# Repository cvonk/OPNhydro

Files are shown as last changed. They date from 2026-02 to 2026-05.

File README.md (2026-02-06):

# OPNhydro - ESP32-C6 Hydroponics Controller

A fully autonomous, data-rich hydroponics automation system with precision control, automatic top-off, and remote monitoring via Home Assistant.

## Features

- **Full Water Quality Monitoring**: pH, EC/TDS, dissolved oxygen, temperature
- **Environmental Monitoring**: Air temp/humidity, light intensity (lux/PPFD), VPD
- **Automatic Dosing**: pH up/down, two-part nutrients (A/B)
- **Automatic Top-Off (ATO)**: Ultrasonic level sensing with user-approved filling
- **Standalone Operation**: Local automation continues if Home Assistant is offline
- **Safety Features**: Float switch interlocks, dosing limits, timeout protection

## Project Structure

```
OPNhydroponics/
├── esphome/                    # ESPHome firmware configuration
│   ├── hydroponics-controller.yaml
│   ├── secrets.yaml.example
│   └── home-assistant-automations.yaml
├── hardware/
│   ├── ARCHITECTURE.md         # System design and pin assignments
│   ├── BOM.md                  # Bill of materials with pricing
│   ├── SCHEMATIC_DESIGN.md     # Circuit design guide
│   └── kicad/                  # KiCad PCB project
│       ├── hydroponics-controller.kicad_pro
│       └── README.md
├── docs/                       # Additional documentation
├── firmware/                   # Custom ESPHome components (if needed)
└── README.md
```

## Hardware Overview

| Category | Selection |
|---|---|
| System Type | NFT (Nutrient Film Technique), 20-80 plants |
| Controller | ESP32-C6-DevKitC-1-N8 (WiFi 6, Thread, USB-C) |
| Sensors | Atlas Scientific EZO (pH, EC, DO) + environmental |
| Actuators | 1× 12V main pump, 4× 12V dosing pumps, 1× 12V ATO valve |
| Integration | Home Assistant via ESPHome, standalone capable |

### Sensor Suite

| Sensor | Interface | Purpose |
|---|---|---|
| Atlas EZO-pH | I2C | Water pH monitoring |
| Atlas EZO-EC | I2C | Nutrient concentration (EC/TDS) |
| Atlas EZO-DO | I2C | Dissolved oxygen |
| DS18B20 | 1-Wire | Water temperature |
| HC-SR04 | GPIO | Water level (ultrasonic) |
| BME280 | I2C | Air temp, humidity, pressure |
| BH1750 | I2C | Light intensity (lux) |
| Float switches | GPIO | Safety level detection |

### Actuators

| Actuator | Voltage | Control |
|---|---|---|
| Main circulation pump | 12V DC | GPIO → MOSFET |
| pH Up dosing pump | 12V DC | GPIO → MOSFET |
| pH Down dosing pump | 12V DC | GPIO → MOSFET |
| Nutrient A dosing pump | 12V DC | GPIO → MOSFET |
| Nutrient B dosing pump | 12V DC | GPIO → MOSFET |
| ATO solenoid valve | 12V DC (NC) | GPIO → MOSFET |

## Quick Start

### 1. Hardware Setup

See [hardware/BOM.md](hardware/BOM.md) for the complete parts list.

**Minimum for testing:**
- ESP32-C6-DevKitC-1-N8 development board
- Atlas Scientific EZO-pH kit (or DFRobot for budget option)
- DS18B20 waterproof temperature probe
- Peristaltic dosing pump (12V)

### 2. ESPHome Configuration

1. Copy `esphome/secrets.yaml.example` to `esphome/secrets.yaml`
2. Fill in your WiFi credentials and generate API keys
3. Update DS18B20 address in the YAML (run I2C scan to find it)
4. Flash to ESP32-C6:

```bash
cd esphome
esphome run hydroponics-controller.yaml
```

### 3. Home Assistant Integration

1. The device will auto-discover in Home Assistant
2. Add the provided automations from `home-assistant-automations.yaml`
3. Create a dashboard with the exposed entities

## Local Automation

The controller runs standalone pH and EC control without Home Assistant:

**pH Control (every 5 minutes):**
- If pH < (target - tolerance): dose pH Up
- If pH > (target + tolerance): dose pH Down
- Respects lockout timer (default 5 min between doses)
- Respects daily limits (default 50 mL/day)

**EC Control (every 10 minutes):**
- If EC < (target - tolerance): dose Nutrient A, then B
- Only doses if pH is within range (5.5-6.5)
- Respects same lockout and daily limits

**ATO (Automatic Top-Off):**
- Monitors water level via ultrasonic sensor
- When level drops below threshold (default 70%), requests approval
- User approves via Home Assistant notification or dashboard
- Fills until target level (95%) or timeout

## Safety Features

1. **Float Switch Interlocks**: Main pump stops if low level detected
2. **ATO Overflow Protection**: High float switch stops fill immediately
3. **Dosing Lockout**: Minimum time between doses prevents overdosing
4. **Daily Limits**: Maximum mL per day for each chemical
5. **Timeout Protection**: ATO fill times out after configurable period
6. **Fail-Safe Valve**: NC (normally closed) solenoid prevents flooding on power loss

## PCB Design

The custom PCB is designed for JLCPCB fabrication:

- **Size**: 100mm × 80mm
- **Layers**: 2-layer
- **Features**: Reverse polarity protection, TVS diodes, proper isolation

See [hardware/kicad/README.md](hardware/kicad/README.md) for design files and manufacturing instructions.

## Configuration Reference

### Setpoints (adjustable via Home Assistant)

| Parameter | Default | Range | Description |
|---|---|---|---|
| pH Target | 6.0 | 5.0-7.5 | Target pH value |
| pH Tolerance | 0.3 | 0.1-1.0 | Deadband before dosing |
| EC Target | 1500 µS/cm | 500-3000 | Target conductivity |
| EC Tolerance | 200 µS/cm | 50-500 | Deadband before dosing |
| Dose Amount | 2.0 mL | 0.5-20 | Per-dose volume |
| Lockout Time | 5 min | 1-30 | Min time between doses |
| Daily pH Limit | 50 mL | 10-200 | Max pH adjustment per day |
| Daily Nutrient Limit | 100 mL | 10-500 | Max nutrients per day |
| ATO Low Threshold | 70% | 50-90 | Level to trigger ATO request |
| ATO High Target | 95% | 80-100 | Level to stop filling |
| ATO Max Fill Time | 180s | 30-600 | Timeout for safety |

### Pin Assignment

See [hardware/ARCHITECTURE.md](hardware/ARCHITECTURE.md) for complete GPIO mapping.

## Cost Estimate

| Category | Cost |
|---|---|
| Microcontroller | $8 |
| Power Management | $15 |
| Water Quality Sensors (Atlas) | $350 |
| Environmental Sensors | $20 |
| Actuators | $75 |
| PCB + Connectors | $40 |
| Enclosure | $25 |
| **Total** | **~$530** |

Budget option with DFRobot sensors: ~$280

## Contributing

This is an open project. Contributions welcome:

- Bug reports and feature requests via Issues
- PCB improvements and alternative designs
- ESPHome component enhancements
- Documentation improvements

## License

See [LICENSE](LICENSE) file.

## Acknowledgments

- [ESPHome](https://esphome.io/) for the excellent ESP32 framework
- [Atlas Scientific](https://atlas-scientific.com/) for quality sensor documentation
- [Home Assistant](https://www.home-assistant.io/) for the automation platform

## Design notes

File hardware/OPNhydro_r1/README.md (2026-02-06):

# KiCad Project - Hydroponics Controller

## Project Setup

### Required KiCad Version
- KiCad 8.0 or later

### Required Libraries

Install these libraries before opening the project:

1. **ESP32 Symbols & Footprints**
   - Source: https://github.com/espressif/kicad-libraries
   - Contains ESP32-C6-WROOM-1 module

2. **Connector Libraries** (included in KiCad)
   - Connector_BarrelJack
   - Connector_JST
   - Connector_USB

3. **Custom/Third-Party**
   - LCSC component library (optional, for JLCPCB assembly)

### Library Installation

```bash
# Clone Espressif KiCad libraries
git clone https://github.com/espressif/kicad-libraries.git

# Add to KiCad:
# Preferences -> Manage Symbol Libraries -> Add (espressif.kicad_sym)
# Preferences -> Manage Footprint Libraries -> Add (espressif.pretty)
```

## Design Specifications

### Board Parameters
- **Size**: 100mm × 80mm
- **Layers**: 2
- **Copper weight**: 2oz (70µm) outer layers
- **Min trace width**: 0.3mm (signal), 1.0mm (power), 2.0mm (high power)
- **Min clearance**: 0.2mm (signal), 0.3mm (power), 0.5mm (high voltage)
- **Via size**: 0.8mm pad / 0.4mm drill
- **Finish**: HASL (lead-free) or ENIG

### Layer Assignment
- **F.Cu (Top)**: Signal routing, component pads
- **B.Cu (Bottom)**: Ground plane, power distribution
- **F.Silkscreen**: Component designators, polarity marks
- **B.Silkscreen**: Board info, version

### Net Classes

| Class | Track Width | Clearance | Via Size | Usage |
|---|---|---|---|---|
| Default | 0.3mm | 0.2mm | 0.8/0.4mm | Signal traces |
| Power | 1.0mm | 0.3mm | 1.0/0.5mm | 3.3V, 5V rails |
| HighPower | 2.0mm | 0.5mm | 1.2/0.6mm | 12V, pump/valve outputs |

## Schematic Hierarchy

```
hydroponics-controller.kicad_sch (Root)
├── power-input.kicad_sch        # 12V input, protection, connectors
├── power-regulators.kicad_sch   # Buck converter (12V→5V), LDO (5V→3.3V)
├── devkit-headers.kicad_sch     # ESP32-C6-DevKitC-1 pin headers
├── sensors-i2c.kicad_sch        # I2C bus, EZO connectors, BME280, BH1750
├── sensors-other.kicad_sch      # 1-Wire, ultrasonic, float switches
├── pump-drivers.kicad_sch       # MOSFET drivers for 6 outputs
└── status-led.kicad_sch         # WS2812B, optional OLED
```

## Component Placement Guidelines

### Critical Placement
1. **DevKit headers**: Center of board, USB-C edge accessible
2. **Buck converters**: Near power input, with heatsinking area
3. **MOSFETs**: Grouped near screw terminals for pumps/valve
4. **BNC connectors**: Board edge for panel mounting
5. **Decoupling caps**: Near EZO circuit power pins

### DevKit Mounting
- ESP32-C6-DevKitC-1-N8 mounts via 2×20 female pin headers (2.54mm pitch)
- Header row spacing: 22.86mm (900 mils)
- No antenna keep-out needed - antenna is on DevKit PCB
- USB-C accessible at DevKit edge

### Thermal Considerations
- MOSFETs: Add thermal vias under source pad
- Buck converters: Large copper pour for heatsinking
- LDO: Thermal pad connected to ground plane

## Connector Pinouts

### J1 - 12V Power Input (3.5mm Pluggable Terminal)
| Pin | Signal |
|-----|---|
| 1 | +12V |
| 2 | GND |

### J2 - Main Pump (3.5mm Pluggable Terminal)
| Pin | Signal |
|-----|---|
| 1 | PUMP+ (12V switched) |
| 2 | PUMP- (GND) |

### J3-J6 - Dosing Pumps (3.5mm Pluggable Terminal each)
| Pin | Signal |
|-----|---|
| 1 | PUMP+ (12V switched) |
| 2 | PUMP- (GND) |

### J7 - ATO Solenoid Valve (3.5mm Pluggable Terminal)
| Pin | Signal |
|-----|---|
| 1 | VALVE+ (12V switched) |
| 2 | VALVE- (GND) |

### J8-J10 - BNC Probe Connectors
- Panel-mount BNC female for pH, EC, DO probes
- Atlas probes use male SMA with included SMA-to-BNC adapter
- Connect to respective EZO circuit PRB input

### J11-J14 - I2C Sensors (JST-PH 4-pin, Qwiic compatible)
| Pin | Signal | Color |
|-----|---|---|
| 1 | GND | Black |
| 2 | 3.3V | Red |
| 3 | SDA | Blue |
| 4 | SCL | Yellow |

### J15 - 1-Wire (JST-PH 3-pin)
| Pin | Signal |
|-----|---|
| 1 | GND |
| 2 | DATA |
| 3 | 3.3V |

### J16 - Ultrasonic Sensor (JST-XH 4-pin)
| Pin | Signal |
|-----|---|
| 1 | VCC (5V) |
| 2 | TRIG |
| 3 | ECHO |
| 4 | GND |

### J17-J18 - Float Switches (JST-XH 2-pin each)
| Pin | Signal |
|-----|---|
| 1 | SWITCH |
| 2 | GND |

## Manufacturing Files

### Gerber Export Settings (JLCPCB)
- Gerber X2 format
- Include: F.Cu, B.Cu, F.Paste, B.Paste, F.Silkscreen, B.Silkscreen, F.Mask, B.Mask, Edge.Cuts
- Drill files: Excellon format, PTH and NPTH combined

### BOM Export
- Export as CSV for JLCPCB assembly
- Include: Reference, Value, Footprint, LCSC Part Number

### Pick & Place
- Export component positions for SMT assembly
- Origin: Aux origin or board origin (check JLCPCB requirements)

## Version History

| Version | Date | Changes |
|---|---|---|
| 1.0 | TBD | Initial design |

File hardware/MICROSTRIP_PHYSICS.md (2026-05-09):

<center>

# Field Theory for PCB Design

**"Signal Integrity from First Principles"**</center>

<figure>
  <center>
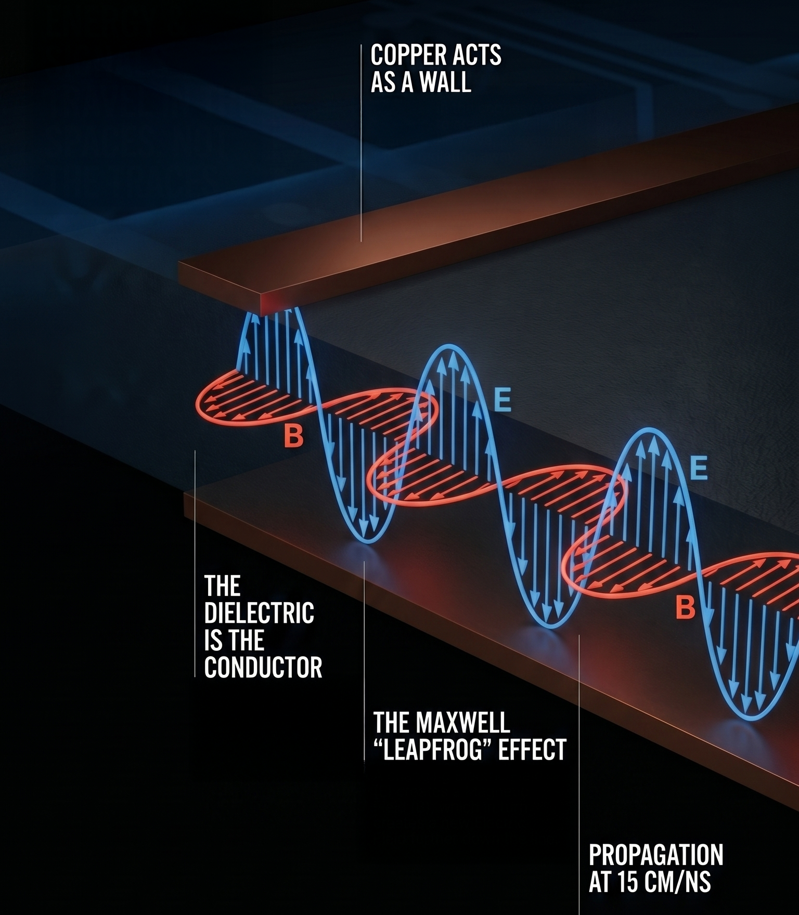
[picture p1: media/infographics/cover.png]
  
  </center>
</figure>
<style>
  .quote {
  position: relative;
  width: 95%;
  padding-left:4% !important;
  /*margin: 0 auto;*/
  /*line-height: 1.4;*/
  z-index: 600;
  overflow: visible;
  /*background-color: #f6f6f6;*/
}
.quote:before {
  position: absolute;
  top: -0.25em;
  left: 0;
  z-index: -300;
  font-family: Georgia, serif;
  content: "\201C";
  color: #999;
  opacity: 0.3;
  font-size: 2.3rem;
  font-weight: 600;
  text-shadow: none;
}
.quote cite {
  color: #bbb !important;
  display: block;
  font-style: normal;
  font-weight: 400;
  text-align: right;
  line-height: 1;
}
.quote.feynman:before {
  color: red;
}
.quote.feynman {
  /*color: cornflowerblue;*/
}
.important-note {
  position: relative;
  border-radius: 8px;
  overflow: hidden;
  padding: .8rem .2rem 0rem 5rem;
  margin: 0 0 1.2rem 0;
  background: #f1f3a2;
  background: -webkit-gradient(
    linear,
    0% 0%,
    0% 100%,
    from(rgba(247, 247, 210, 1)),
    to(rgba(240, 242, 155, 1))
  );
  background: -moz-linear-gradient(
    top,
    rgba(247, 247, 210, 1),
    rgba(240, 242, 155, 1)
  );
}
.important-note p {
  margin: 0;
  padding: 0;
}
.important-note .katex-display {
  margin: 4px;
}
.important-note .MathJax_Preview {
  display: none;
}
.important-note .icon {
  font-weight: 700;
  background: #ff7a18;
  background: -webkit-gradient(
    linear,
    0% 0%,
    0% 100%,
    from(#ffad71),
    to(#ff7a18)
  );
  background: -moz-linear-gradient(top, #ffad71, #ff7a18);
  color: #fff;
  padding: 0 0.3rem;
  font-size: 40px;
  margin-right: 0rem;
  position: absolute;
  left: 0;
  top: 0;
  height: 100%;
  width: unset;
  display: flex;
  align-items: center;
}
</style>

Modern high-speed electronic systems cannot be understood using lumped circuit models alone[^cantExplain]. As signal transition times decrease, the spatial extent of electromagnetic fields becomes comparable to the physical dimensions of PCB interconnects. Under these conditions, signal behavior is governed by the propagation of electromagnetic waves rather than by instantaneous circuit relationships.

Voltage and current remain useful quantities, but they are not fundamental. They arise from the underlying electric and magnetic fields, $\mathbf E$ and $\mathbf B$, which evolve in space and time according to Maxwell’s equations.
[^cantExplain]: Circuit theory cannot explain why a split in the ground plane causes a signal integrity problem, why energy travels in the dielectric rather than in the copper, or why crosstalk depends on field geometry rather than circuit topology.

A PCB trace together with its return path forms a transmission structure that guides electromagnetic energy. The conductors do not carry this energy in the conventional sense; instead, they establish boundary conditions that shape and confine the fields. The dominant portion of the signal energy resides in the dielectric region between conductors.

This field-based perspective provides a unified framework for understanding:
- signal propagation and transmission-line behavior
- crosstalk between adjacent traces
- power distribution network (PDN) transients
- electromagnetic interference (EMI) and radiation

Throughout this document, circuit models are used where appropriate, but always as approximations derived from the underlying field behavior.

Chapter 1 builds the field theory picture from first principles — starting with Maxwell's equations applied to a microstrip, and working through wave propagation, conductor response, rail collapse, crosstalk, and EMI. Chapter 2 translates that physics into concrete layout rules, stack-up choices and trace sizing.

<br />

---

<br />

## 1 Field Theory

> "Since the TTL days, there has been a four orders of magnitude change in the switching speed of transistors."  -- *Dan Beeker*

<br />

### 1.1 From Voltage Step to Electromagnetic Wave in the Dielectric

> "Energy and signals travel in the spaces not the traces"  -- *Ralph Morrison*

When a voltage step is applied to a PCB trace, it triggers the propagation of a coupled electromagnetic disturbance guided by the geometry of the conductors and the dielectric.

We examine how such a disturbance is created and how it propagates.
<br />

#### 1.1.1 Physical Setup

Consider a **microstrip** structure consisting of:
- a conducting trace,
- a return plane,
- a dielectric separating them.

<figure>
  <center>
  
  <figcaption><i>3D-view of the microstrip structure.</i></figcaption>
  </center>
</figure>

We define a right-handed coordinate system ($\hat x \times \hat y = \hat z$):
- **$\hat x$:** from the trace down to the return plane (normal to the conductors, through the dielectric)
- **$\hat y$:** transverse to the trace (in the plane of the board, perpendicular to the trace direction)
- **$\hat z$:** direction of propagation

A voltage step is applied at one end of the trace. The central question is: 

<div class="quote">

**What physical mechanism carries this signal forward?**
</div>
<br />

#### 1.1.2 Governing Equations

The fields are governed by two of [Maxwell's equations](https://coertvonk.com/physics/electromagnetism/magnetism/materials-and-maxwells-equations-30453):
$$  
  \begin{align}  
    \nabla \times \mathbf E &= -\frac{\partial \mathbf B}{\partial t}
    \tag{\text{Faraday}}
    \\
    \nabla \times \mathbf B &=
    \mu\,\mathbf J
    +\ 
    \mu\,\varepsilon\, \frac{\partial \mathbf E}{\partial t}
    \tag{\text{Ampère-Maxwell}} 
  \end{align}
$$ 

where:
- $\mathbf E$ is the electric field vector at each point in space
- $\mathbf B$ is the magnetic field vector at each point in space
- $\mathbf J$ is the conduction current density
- $\mu$ and $\varepsilon$ are constants for the material

In the dielectric region:
- no free charges: $\rho = 0$
- no conduction current: $\mathbf J = \mathbf 0$

<div class="important-note"><span class="icon">💡</span>

In the dielectric, the two equations reduce to:
$$
  \begin{align*}
    \nabla \times \mathbf{B} &= \color{red}\cancel{\color{black}\mu \, \mathbf{J}} \color{black} + \mu\,\varepsilon \frac{\partial \mathbf{E}}{\partial t}
    \tag{\text{source-free Ampère-Maxwell}} \\
    \nabla \times \mathbf{E} &= -\frac{\partial \mathbf{B}}{\partial t}
    \tag{\text{Faraday}}
  \end{align*}
$$
</div>

These relations show that **time-varying electric and magnetic fields generate each other**.
<br />

#### 1.1.3 Intuitive Picture

<div class="quote feynman">

  Now look — you've got a copper trace, and underneath it a big sheet of copper called the return plane. Between them, a thin slab of dielectric. That's it. That's the whole apparatus. And I want to tell you what happens when you flip a switch at one end and connect a battery.

  The instant you close the switch, there's a voltage between the trace and the plane. And whenever you have a voltage between two pieces of metal, there's an **electric field** between them. Bang — the field is just there, pointing from the trace down to the plane. Not in all of space, mind you — only right near the switch, because the rest of the trace hasn't heard the news yet.

  Now, here is where it gets interesting. The electric field went from zero to something. That's a change. And it turns out — and this is one of the most marvelous things in physics — that **a changing electric field makes a magnetic field**. Not "has a magnetic field associated with it." Makes one. Maxwell figured this out. The electric field changes in time, and a magnetic field curls up around it, right there in the dielectric.

  OK, so now we have a magnetic field. And it is also going from zero to something. It's changing in time too. And Faraday — long before Maxwell — figured out the other half of the story: **a changing magnetic field makes an electric field**. So the magnetic field we just made, by changing, makes another electric field — a little bit further along the trace than the one we started with.

  You see what's happening? The electric field made a magnetic field. The magnetic field made an electric field. The new electric field is further down the line. And now it is changing, so it makes another magnetic field, which makes another electric field, and off we go. The two fields are playing leapfrog[^LEAPFROG], and they're heading down the trace at an enormous speed.

  And how fast, exactly? In empty space these fields travel at the speed of light — that's what light *is*, by the way, the same kind of leapfrog. In the dielectric the fields go a little slower because the dielectric gets in their way. But still fast — about half the speed of light. Six inches in a nanosecond. *That's* how fast a signal really moves on your board.

  And that, really, is what every trace on every PCB is doing. It's not carrying electrons to some destination. It's guiding a little wave of energy. Isn't that something?
</div>

[^LEAPFROG]: In reality the two fields coexist at every point, but the "leapfrog" picture captures how each sustains the other.

<figure>
  <center>
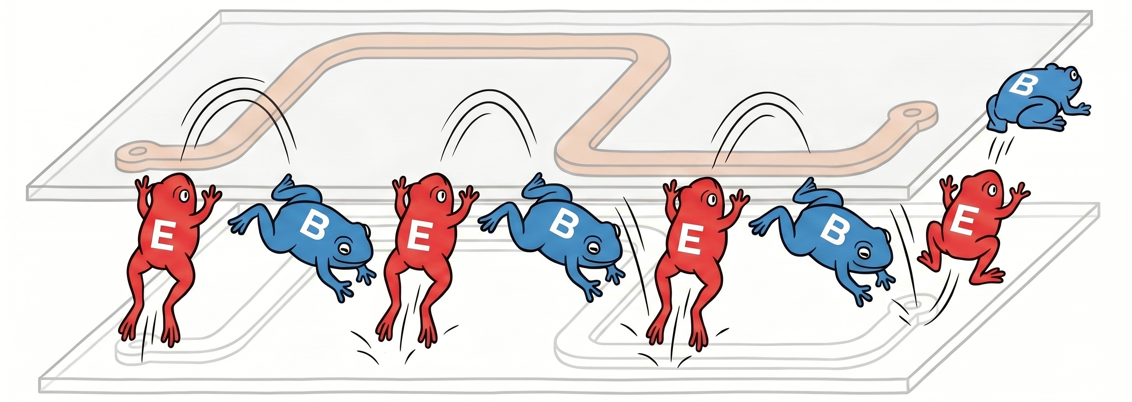
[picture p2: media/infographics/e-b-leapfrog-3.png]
  
  </center>
</figure>
<br />

#### 1.1.4 Wave Propagation Mechanism

<figure>
  <center>
  
  <figcaption><i>Side-view of the wavefront propagating along the trace, with <b>E</b> pointing from trace to return plane.</i></figcaption>
  </center>
</figure>

The intuition above pictures the wave as a sequence of E → B → E events. Maxwell's equations make this precise: a time variation at one point forces a spatial variation, and the wave's coherence comes from the two laws being applied everywhere simultaneously.

When a **voltage step** is applied to the trace:

1. An **electric field is established** ($\mathbf E$), between the trace and the return plane, near the source. Because it rises from zero, it is **time-varying**.
<br />

2. According to the Ampère–Maxwell law, an electric field in the $x$-direction that varies along the $z$-axis ($\tfrac{\partial E_x}{dt}\gt 0$) causes a **magnetic field** in the $y$-direction ($B_y$) that varies with $z$ — that means a little further along $z$, its value is rising from zero; it is **time-varying**. <details><summary>Expand if you ❤️ to see the derivation.</summary>
$$
  \begin{align*}
    \nabla \times \mathbf{B} &= \mu\,\varepsilon \frac{\partial \mathbf{E}}{\partial t}
    &({\text{Ampère-Maxwell}}) \\  
    \nabla\times\mathbf B &=
    \mu\varepsilon\frac{\partial E_x}{dt}\hat x, &(\mathbf{E}=E_x\,\hat x) \\
    \left(\frac{\partial B_z}{dy} - \frac{\partial B_y}{\partial z}\right)\cancel{\hat x} + \bcancel{\left(\ldots\right) \hat y} + \bcancel{\left(\ldots\right) \hat z} &=
    \mu\varepsilon\frac{\partial E_x}{dt} \cancel{\hat x}, &(\text{like terms}) \\
    -\frac{\partial B_y}{\partial z} &=
    \mu\varepsilon\frac{\partial E_x}{dt}, &(\frac{\partial B_z}{dy}=0)
  \end{align*}
$$
</details>
<br />

3. According to Faraday's law, an magnetic field in the $y$-direction that varies along the $z$-axis ($\tfrac{\partial B_y}{dt}\gt 0$) causes a **electric field** in the $x$-direction ($E_x$) that varies with $z$ — that means a little further along $z$, its value is rising from zero; it too is **time-varying**, and the disturbance has moved forward.[^leapfrogRigor]. <details><summary>Expand if you ❤️ to see the derivation.</summary>
$$
  \begin{align*}
    \nabla \times \mathbf{E} &= -\frac{\partial \mathbf{B}}{\partial t}
    &({\text{Faraday}}) \\  
    \nabla\times\mathbf E &=
    -\frac{\partial B_y}{dt}\hat y, &(\mathbf{B}=B_y\,\hat y) \\
    \bcancel{\left(\ldots\right)\hat x} + \left(\frac{\partial E_x}{\partial z} - \frac{\partial E_z}{\partial x}\right)\cancel{\hat y} +\bcancel{\left(\ldots\right)\hat z} &=
    -\frac{\partial B_y}{\partial t} \cancel{\hat y} & (\text{like terms}) \\
    \frac{\partial E_x}{\partial z} &=
    -\frac{\partial B_y}{dt}, &(\frac{\partial E_x}{dx}=0)
  \end{align*}
$$
</details>
<br />

Steps 2 and 3 continue throughout the structure. The result is not the transport of charge along the conductor, but the propagation of a **self-sustaining electromagnetic wave**.

Two conditions are essential:
- **Temporal variation:** the fields change in time at each point.
- **Spatial variation:** the fields differ from one location to another.

Together, they enforce propagation.

<div class="important-note"><span class="icon">💡</span>A voltage step on a trace and return plane launches an electromagnetic wave in the dielectric.
<br />
<br />
</div>

[^leapfrogRigor]: The "a little further down the line" framing in steps 2 and 3 is the leapfrog picture — useful for intuition, slightly loose as physics. The rigorous version: Maxwell-Ampère couples $\partial \mathbf E/\partial t$ here to $\partial \mathbf B/\partial z$ here, and the wavefront constraint $\partial/\partial t = -v\,\partial/\partial z$ converts the time variation into a spatial one. Appendix A.1 derives this coupling from Maxwell-Ampère; Appendix A.3 derives the wavefront constraint.

<br />

#### 1.1.5 Wave Equation and Velocity

The $\mathbf{E}$-field wave equation follows when you combine Faraday's law, the source-free Ampère–Maxwell law and Gauss's law.

<details>
  <summary>Expand if you ❤️ to see the derivation.</summary>

  Take the curl of Faraday's law
  $$
      \nabla \times (\nabla \times \mathbf E) = -\frac{\partial}{\partial t}(\nabla \times \mathbf B)
  $$

  Substitute the source-free Ampère–Maxwell into the right side
  $$
      \nabla \times (\nabla \times \mathbf E) = -\mu\,\varepsilon \frac{\partial^2 \mathbf E}{\partial t^2}
  $$

  Recall the vector identity
  $$
      \nabla \times (\nabla \times \mathbf E) = \nabla(\nabla \cdot \mathbf E) - \nabla^2\mathbf E
      \tag{\text{vector identity}}
  $$

  Expand the left side using this vector identity
  $$
      \nabla(\nabla \cdot \mathbf E) - \nabla^2\mathbf E = -\mu\,\varepsilon \frac{\partial^2 \mathbf E}{\partial t^2}
  $$

  Apply Gauss's law:
  $$
      \nabla \cdot \mathbf E = \frac{\rho}{\varepsilon}
      \tag{\text{Gauss}}
  $$

  In the source-free dielectric there are no charges ($\rho = 0$), so this becomes $\nabla \cdot \mathbf E = 0$. The first term vanishes, leaving:
  $$
      -\nabla^2 \mathbf E = -\mu\,\varepsilon\, \frac{\partial^2 \mathbf E}{\partial t^2}
  $$

  Or equivalently, the wave equation:
  $$
      \nabla^2 \mathbf E = \mu\,\varepsilon\, \frac{\partial^2 \mathbf E}{\partial t^2}
  $$
</details>
<br />

<div class="important-note"><span class="icon">💡</span>

Combining Faraday and Ampère-Maxwell yields the standard wave equation
$$
    \nabla^2 \mathbf E = \underbrace{\mu\,\varepsilon}_{1/v^2} \,\frac{\partial^2 \mathbf E}{\partial t^2}
$$
</div>

In this we recognize the generic wave equation for any quantity propagating at speed $v$:
<div class="quote">

$$
    \nabla^2 f = \frac{1}{v^2} \ \frac{\partial^2 f}{\partial t^2}
    \tag{\text{generic wave}}
$$
</div>

Comparing the two, term by term, gives the wave speed $v$:

<div class="important-note"><span class="icon">💡</span>

The propagation speed is only determined by material properties
$$
  v = \frac{1}{\sqrt{\mu \, \varepsilon}}
$$

where:
- $v$ is the wave speed
- $\mu$ is the permeability of the material
- $\varepsilon$ is the permittivity of the material 
</div>

<details>
  <summary>Expand to ❤️ how this gives the speed of light.</summary>

  In vacuum, the permeability constant $\mu = \mu_0$, and the permittivity constant $\varepsilon = \varepsilon_0$.
  $$
    \left\{
      \begin{align*}
        \mu_0 &= 4\pi \times 10^{-7} \text{ H/m} \\
        \varepsilon_0 &= 8.854 \times 10^{-12} \text{ F/m}
      \end{align*}
    \right.
  $$

  Substituting these constants:
  $$
      v = \frac{1}{\sqrt{4\pi \times 10^{-7} \times 8.854 \times 10^{-12}}} \approx 299.8 \times 10^6 \text{ m/s}
  $$

  That is the speed of light $c$ — derived entirely from electric and magnetic constants.
</details>
<br />

**In the dielectric** in a microstrip, the medium is not homogeneous (fields exist in both dielectric and air), and the mode is quasi-TEM rather than pure TEM. The propagation velocity (call it $v'$) is therefore determined by an **effective permittivity $\varepsilon_{\text{eff}}$**, so $\varepsilon = \varepsilon_{\text{eff}}\,\varepsilon_0$. The effective value is smaller than the bulk relative permittivity because part of the field is in air. For typical FR-4 microstrip ($\varepsilon_{\text{eff}} \approx 3.5$; bulk FR-4 has $\varepsilon_r \approx 4.3$):
$$
    v' = \frac{1}{\sqrt{4\pi \times 10^{-7} \times 3.5 \times 8.854 \times 10^{-12}}} \approx 16 \text{ cm/ns}
$$
<br />

#### 1.1.6 Interpretation

The signal does not propagate as a moving charge. The wave is the spatial pattern of $\mathbf E$ and $\mathbf B$ advancing through the dielectric, with the conductor surfaces forming the boundary that guides it. Energy resides in the dielectric volume, not in the copper.

For design, this reframes what a trace actually is. A trace is not a wire that carries current — it is one wall of a guiding structure whose other wall is the return plane. The integrity of the wave depends on what happens between those two walls. If the dielectric, the trace, and the return plane together form a clean boundary, the wave propagates undisturbed. If any one of them is compromised, the wave is disrupted, and the signal pays the price.

§1.2 examines what the conductors actually do to make this work: not transporting energy, but enforcing the boundary conditions that let the wave exist at all.
<br />

#### 1.1.7 Summary

A voltage step launches an electromagnetic wave that propagates in the dielectric, guided by the trace and its return plane. The propagation velocity is determined by material properties — about 16 cm/ns for FR-4 microstrip. The conductors do not carry the signal; they shape the boundary that lets the wave exist.
<br />

---

<br />

### 1.2 Conductor Response: Surface Charge and Current

Section 1.1 established that signal propagation occurs as an electromagnetic wave in the dielectric. The conductors do not transport the signal energy; instead, they respond to the incident fields and enforce the boundary conditions required for the wave to exist.

<div class="important-note"><span class="icon">💡</span>

**The wave is primary; the conductor response is a consequence.** The wave in the dielectric drives surface charge and surface current on the copper. Those surface quantities exist because Maxwell's equations require them at the boundary — not because they carry the signal.
</div>

The **free electrons** in the conductor respond in two forms:
- **surface charge**, associated with the electric field
- **surface current**, associated with the magnetic field

Both arise directly from Maxwell’s equations.
<br />

#### 1.2.1 Electric Field at the Conductor Boundary

In a microstrip, the electric field in the dielectric has two components:
- a dominant **normal** component $E_x$, perpendicular to the conductor surfaces (along the dielectric thickness)
- a smaller **longitudinal** component $E_z$, along the direction of propagation

<figure>
  <center>
  
  <figcaption><i>Side-view: E<sub>x</sub> (normal, dominant) and E<sub>z</sub> (longitudinal, small) components of the microstrip electric field.</i></figcaption>
  </center>
</figure>

These components produce distinct physical effects at the conductor surface.
<br />

#### 1.2.2 Intuitive Picture

<div class="quote feynman">

  So put it all together:
  - The wave is in the dielectric.
  - The *down-field* from the wave shoves electrons around on the copper surfaces. Those electrons build a wall that keeps the wave trapped in the dielectric.
  - The *along-field* from the wave pushes other electrons along the trace, giving you the little current you measure with your ammeter.

  And here's a small puzzle. Once the wavefront has passed your section, the wall of charge is built — fine, that's what walls do. But the *current* keeps flowing. Why? Because the wavefront is still out there ahead of you, still building walls farther down the line, and it needs charge to do it. The current through your already-charged section is feeding the section in front of you — like water in a pipe still flowing because somebody downstream is still drinking.

  The wave is the boss. The electrons are the help. And what the electrons do — the thing we call "current" — is not how the energy gets from here to there. The energy is out in the dielectric, in the fields. The current is just the electrons reacting to the field.

  You can also say this without ever mentioning an electron. The wave's $\mathbf E$ and $\mathbf B$ exist right up to the surface of the copper, but inside the copper they have to be zero — that's what good conductors do. So there's a jump at the surface, and nature does not allow that for free: wherever the perpendicular $\mathbf E$ has a jump, there must be **charge** to account for it; wherever the parallel $\mathbf B$ has a jump, there must be **current**. The metal has no choice.

  And that's really all there is to it. The hard part is believing it.
</div>

> Translating into formal terms: 
> - "down-field" → normal $E_x$ (perpendicular to the conductor surfaces);
> - "along-field" → longitudinal $E_z$ (along the direction of propagation).

<br />

#### 1.2.3 Surface Charge Formation (driven by $E_x$)

As the wavefront reaches a section of the conductor, the normal electric field $E_x$ rises from zero to a finite value.

This field exerts a force on the **free electrons**:
- *in the trace*, electrons move away from the dielectric-facing surface.
- *in the return plane*, electrons move toward the dielectric-facing surface.
<figure>
  <center>
  
  <figcaption><i>Side-view: Microstrip E<sub>x</sub> confinement.</i></figcaption>
  </center>
</figure>

This redistribution produces:
- **positive surface charge** on the underside of the trace
- **negative surface charge** on the top of the return plane

The system rapidly reaches a local equilibrium in which:
- The *net field inside the conductor is driven to zero*, because the surface charges generate their own electric field that opposes the external field.
- The *external field is confined to the dielectric*, since the electric field cannot extend into the conductor.
<br />

##### Boundary Condition

Following the more intuitive discussion above, here's the formal version.

<details>
  <summary>Expand if you ❤️ to see the derivation</summary>

  Imagine a conductor with a surface charge density $\sigma_s$ (charge per unit area) and normal vector $\hat n$ that points perpendicular to the conductor surface. To find the electric field just outside the surface, we place a very thin, small, cylindrical Gaussian "pillbox" so that it straddles the conductor surface.
  <figure>
    <center>
    
    <figcaption><i>Side-view close-up of pillbox straddling the trace/dielectric boundary.</i></figcaption>
    </center>
  </figure>

  Gauss's law in integral form states that the net electric flux through any closed surface ($S$) is directly proportional to the total electric charge ($Q_{enc}$) enclosed within that surface.

  <div class="quote">

  $$
      \oint_S \mathbf E \cdot d\mathbf a = \frac{Q_{enc}}{\varepsilon} \tag{\text{Gauss}}
  $$
  </div> 

  where $d \mathbf{a}$ is an infinitesimal vector element of the surface area, pointing outwards normal to the surface.

  A key property of a conductor in electrostatic equilibrium is that the electric field $\mathbf {E}$ inside the conducting material is zero, so the inside area doesn't contribute. With the height $h \to 0$, the side areas do not contribute either. This implies that the only flux passing through the pillbox comes from the bottom face.
  $$
    \begin{align*}
      \oint_{out} \mathbf E \cdot (A \hat n) &= \left( \mathbf{E} \cdot \hat n \right) A = \frac{Q_{enc}}{\varepsilon} \tag{$d\mathbf{a_{out}}=A\hat n$} \\
      \Rightarrow
      \varepsilon \left(\mathbf{E}\cdot\hat n \right)A &= Q_{enc} \tag{$Q_{enc} = \sigma_s A$}
    \end{align*}
  $$

  The enclosed charge is $Q_{enc} = \sigma_s A$
  $$
      \varepsilon \left(\mathbf{E}\cdot\hat n \right) \bcancel{A} = \sigma_s \bcancel{A}
  $$

  $\mathbf{E}\cdot\hat n$ is the component of the field normal to the surface ($E_x$):
  $$
      \varepsilon\, E_x = \sigma_s
  $$
</details>
<br />

<div class="important-note"><span class="icon">💡</span>

The relationship between surface charge density and the electric field follows from Gauss’s law:
$$
    \sigma_s = \varepsilon\, E_x
$$

where:
- $\sigma_s$ is the surface charge density (in C/m<sup>2</sup>).
- $E_x$ is the electric field just outside the conductor.
</div>

This surface charge distribution is not arbitrary. It is exactly the distribution required to:
- cancel the field inside the conductor
- confine the external field to the dielectric

Thus, **the conductor shapes the electric field** through the formation of surface charge.
<br />

#### 1.2.4 Surface Current (driven by $\mathbf B$ and $E_z$)

This section presents two views of the surface current — the same two arguments the intuition foreshadowed:
1. Given a magnetic field at the surface, what current must exist? ($\mathbf B \to \mathbf K$) — the formal "$\mathbf B$-jump → current" boundary argument.
2. How does current get established as the wave propagates? ($E_z \to \mathbf J$) — the dynamical "along-field pushes electrons" picture.
<br />

##### Magnetic Field $\mathbf B$ drives the need for a Surface Current

The magnetic field associated with the propagating wave is tangential to the conductor surface. Maxwell’s equations require that this field be supported by current at the boundary.

When the magnetic field from the trace tries to enter the return plane, it induces [eddy currents](https://coertvonk.com/physics/electromagnetism/magnetism/motional-emf-30242) that create their own opposite magnetic field. This prevents the magnetic field $\mathbf{B}$ from entering. The return plane is electrically large and a good conductor, so the field cannot escape underneath it either; it has no other choice but to **loop tightly around the trace** in the dielectric above.
<figure>
  <center>
  
  <figcaption><i>Cross-section of the microstrip. <b>B</b>-field curls around the trace.</i></figcaption>
  </center>
</figure>

<details>
  <summary>Expand if you ❤️ to see the derivation</summary>

  Zooming in on a small section of the trace/dielectric boundary, we see that the wave's $\mathbf B$ field is tangential to the trace surface. 
  <figure>
    <center>
    
    <figcaption><i>Cross-section close-up of Amperian loop straddling the trace/dielectric boundary.</i></figcaption>
    </center>
  </figure>

  Imagine a tiny rectangular "Amperian loop" straddling the bottom surface of the copper. Two sides — represented by the displacement vector $\mathbf L$ — run parallel to the surface (one inside the copper, one outside). Two sides of height $h$ run perpendicular to the surface.

  As we shrink the height $h \to 0$, the perpendicular sides contribute nothing. Inside the conductor, $\mathbf{B}_{in} = 0$. Therefore, the total path integral comes entirely from the outside leg:
  $$
    \oint \mathbf{B} \cdot d \mathbf{l} = \mathbf{B}_{out} \cdot \mathbf{L}
  $$

  The current passing through this loop is the surface current density $\mathbf K$ (amps per meter) crossing the loop, integrated along $\mathbf L$:
  $$
    I_{enc} = \mathbf K \cdot \mathbf L
  $$

  (Both $\mathbf B_{out}$ and $\mathbf K$ end up parallel to $\mathbf L$ along the outside leg, so each dot product reduces to a magnitude product $B_{out}\,L$ and $K\,L$.)

  Recall Ampère's law in integral form:
  <div class="quote">

  $$
    \oint \mathbf{B} \cdot d\mathbf{l} = \mu\, I_{enc}
  $$
  </div>

  Substitute $\oint \mathbf{B}\cdot d\mathbf{l}$ and $I_{enc}$ in Ampère's law:
  $$
    \begin{align*}
      \mathbf{B}_{out} \cdot \mathbf{L} &= \mu \left( \mathbf K \cdot \mathbf L \right) \\
      \Rightarrow\quad B_{out}\,\bcancel{L} &= \mu\, K\,\bcancel{L} \\
      \Rightarrow\quad \mathbf K &= \frac{1}{\mu}\,(\hat n \times \mathbf B_{\text{out}}) = \frac{1}{\mu}\, |\mathbf B_{\text{out}}|\, \hat z & \text{(right-hand rule)}
    \end{align*}
  $$ where $\hat n$ is the outward normal from the conductor. 
</details>
<br />

<div class="important-note"><span class="icon">💡</span>

Ampère's law forces a surface current [^sCurrent] in the propagation direction on the **trace**:
$$
    \mathbf K_{\text{trace}} = \frac{B_y}{\mu}\,\hat z
$$

The **return plane** carries an equal and opposite current (its outward normal is $-\hat x$, so the right-hand rule flips the sign):
$$
    \mathbf K_{\text{plane}} = -\frac{B_y}{\mu}\,\hat z
$$

where:
- $\mathbf{K}$ is the surface current in A/m
- $B_y$ is the transverse component of the magnetic field at the boundary

[^sCurrent]: $\mathbf K$ and $\sigma_s$ are **surface** densities — the boundary counterparts of the volume densities $\mathbf J$ (A/m², current per cross-sectional area) and $\rho$ (C/m³, charge per volume). In a *perfect conductor*, all the response squeezes into an infinitely thin layer at the surface, so the volume densities formally become delta-functions and the meaningful quantities are $\sigma_s$ (C/m²) and $\mathbf K$ (A/m).
</div>

This shows that:
- the **magnetic field determines the surface current**
- the current is not an independent driver, but a response to the field

In real conductors, this current is distributed over a thin layer of thickness equal to the **skin depth**, where the fields penetrate slightly into the material. The skin depth $\delta$ is approximately 2 μm in copper at 1 GHz (see Appendix A.4).

For a real conductor, the surface-current approximation $\mathbf K \approx \mathbf J \cdot \delta$ holds for as long as $\delta \ll d$, where $d$ is the thickness of the conductor.

<br />

##### Longitudinal Electric Field $E_z$ establishes the Surface Current

While the previous result expresses a boundary condition, the current must also be established dynamically as the wave propagates.

At the wavefront, the voltage varies rapidly with position, changing from full intensity behind the wave to zero ahead of it. This produces a longitudinal electric field ($E_z$):
$$
  E_z = - \frac{\partial V}{\partial z}
$$

<figure>
  <center>
  Current at the wavefront, driven by the longitudinal field E<sub>z</sub>.
  <figcaption><i>Side-view: Current at the wavefront, driven by E<sub>z</sub>.</i></figcaption>
  </center>
</figure>

This field drives electron drift along the conductor, giving rise to **conduction current**:
- *in the trace*, electrons drift opposite to the direction of propagation
- *in the return plane*, electrons drift in the direction of propagation

This is the dynamic mechanism by which the current required by the magnetic field boundary condition is created.
<br />

##### Charge–Current Coupling (Continuity)

As the wavefront advances:
- surface charge builds up on newly reached sections
- current flows to supply this charge

Surface charge and current are linked by the Continuity Equation, a fundamental law in physics that expresses the conservation of charge.
$$
  \nabla\cdot \mathbf J + \frac{\partial \rho}{\partial t} = 0
  \tag{Continuity}
$$

In surface form:
$$
  \nabla_s \cdot \mathbf K + \frac{\partial \sigma_s}{\partial t} = 0
$$

<details>
  <summary>Expand if you ❤️ to see the derivation</summary>

  The surface divergence operator $\nabla_s\cdot$ takes derivatives only in directions tangent to the surface — for our trace surface with normal $\hat x$, that's $\hat y$ and $\hat z$:
  $$
    \left(
    \frac{\partial K_y}{\partial y} + \frac{\partial K_z}{\partial z} \right)
    + \frac{\partial \sigma_s}{\partial t} = 0
  $$

  Surface current $\mathbf{K}$ only exists in the $z$-direction ($\mathbf{K} = K_z \hat z$), so we can rewrite this as:
  $$
    \bcancel{\frac{\partial K_y}{\partial y}}
    + \frac{\partial K_z}{\partial z}
    + \frac{\partial \sigma_s}{\partial t} = 0
  $$

  Recall the expression for the surface current $\mathbf K$ from the previous section:
  <div class="quote">

  $$
    \mathbf K = \frac{B_y}{\mu}\,\hat z
  $$
  </div>

  As we saw, $\mathbf{K}$ exists only in the $+z$-direction:
  $$
    K_z = \frac{B_y}{\mu}
  $$

  At the wavefront, $\sigma_s$ is ramping from zero to $\varepsilon E_x$ as the wave passes, so $\partial K_z/\partial z \neq 0$ — the current converges into the section to deposit the new charge.

  Because the wave moves at speed $v$, the field follows the form $E_x(z-vt)$. This **wavefront constraint** links a *change in time* to a *change in space*:
  $$
    \frac{\partial E_x}{\partial t} = -v\, \frac{\partial E_x}{\partial z}
  $$

  So $\partial/\partial t = -v\,\partial/\partial z$ for any field quantity. Apply that to surface charge conservation:
  $$
      \frac{\partial K_z}{\partial z} = v\,\frac{\partial \sigma_s}{\partial z}
  $$

  Integrate along $z$ on both sides. Both $K_z$ and $\sigma_s$ vanish ahead of the wavefront, so the integration constant is zero, leaving:
  $$
      K_z = v\,\sigma_s
  $$
  The surface current and surface charge are locked together by the wave speed.
</details>
<br />

<div class="important-note"><span class="icon">💡</span>

For a uniformly propagating wave, this leads to:
$$
  K_z = v\,\sigma_s
$$

where:
- $K_z$ is the longitudinal component of the surface current (along the propagation direction)
- $v$ is the propagation speed
- $\sigma_s$ is the surface charge density
</div>

This relation holds for a traveling wave and expresses that:
- surface charge and current move together
- both are part of the same propagating field structure
<br />

#### 1.2.5 Behavior Behind the Wavefront

Once the wavefront has passed:
- the normal field ($E_x$) becomes steady
- the longitudinal field ($E_z$) becomes small but nonzero (to sustain current against resistive losses in the conductor)

The surface charge at a given section is established once the wave has passed, but **current continues** through that section to supply the wavefront still advancing ahead.
<br />

#### 1.2.6 Interpretation

The conductor does not carry the signal in the conventional sense. Instead:
- **surface charge** enforces electric-field boundary conditions
- **surface current** sustains the magnetic field
- **electron motion is local**, responding to the passing wave

The signal itself remains a propagating electromagnetic field.

For design, this means surface charge and surface current are *consequences* of the wave, not independent variables. They cannot be controlled directly — they are whatever the wave demands at the boundary. Controlling them therefore reduces to controlling the wave's geometry: the trace shape, the dielectric thickness, the continuity of the return plane. Every layout decision that follows in chapter 2 is a way of shaping the wave so the conductor response stays clean and predictable. The next two sections build on this: §1.3 shows that the same wave that drives surface current also produces displacement current in the dielectric, closing the magnetic-field loop; §1.4 shows that growing or reshaping a current loop costs energy, and that this cost is what limits how fast a chip can switch.
<br />

#### 1.2.7 Summary

The response of a conductor to a propagating electromagnetic wave consists of:
- surface charge determined by the electric field
- surface current determined by the magnetic field

These quantities are fully constrained by Maxwell’s equations and are not independent drivers of signal propagation.
<br />

---

<br />

### 1.3 Sources of the Magnetic Field

Sections §1.1 and §1.2 established that signal propagation is an electromagnetic wave in the dielectric, and that the conductors respond through surface charge and current. We here examine a fundamental question:

> **What sustains the magnetic field as it spans both dielectric and conductor regions?**

<figure>
  <center>
  
  <figcaption><i>Cross-section of the microstrip. <b>B</b>-field curls around the trace.</i></figcaption>
  </center>
</figure>

<details>
  <summary>Expand if you ❤️ to see the simulated fields</summary>

  <figure>
    <center>
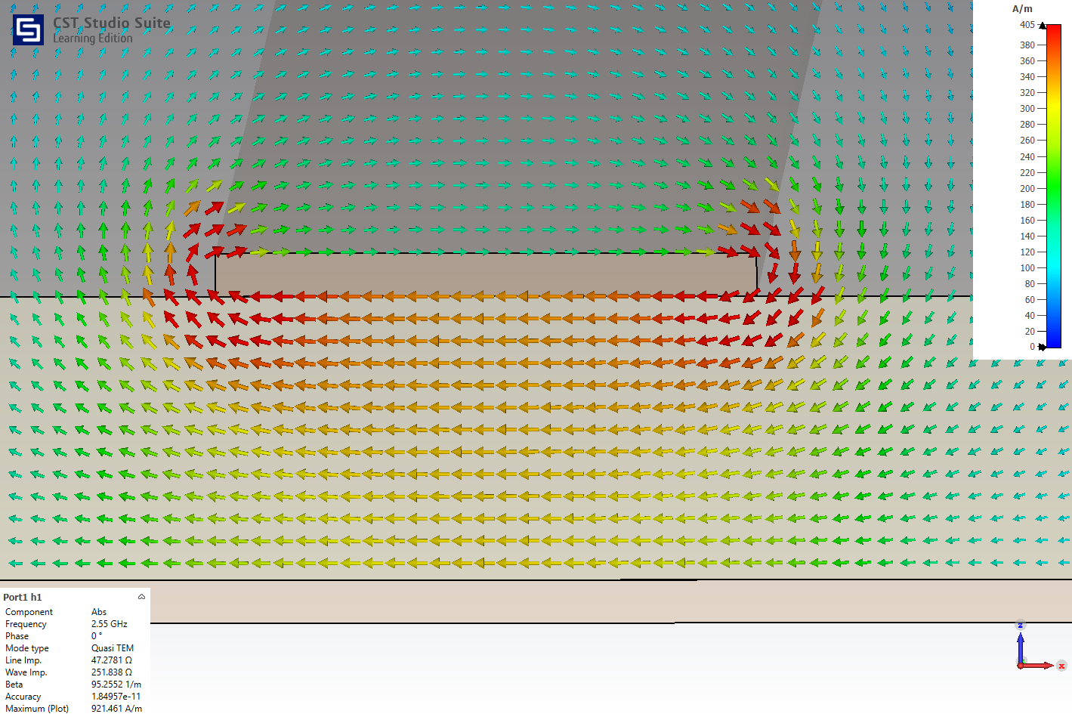
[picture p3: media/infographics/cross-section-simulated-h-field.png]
    
    <figcaption><i>Cross-section of the microstrip. CST simulation of <b>B</b>-field.</i></figcaption>
    </center>
  </figure>

  <figure>
    <center>
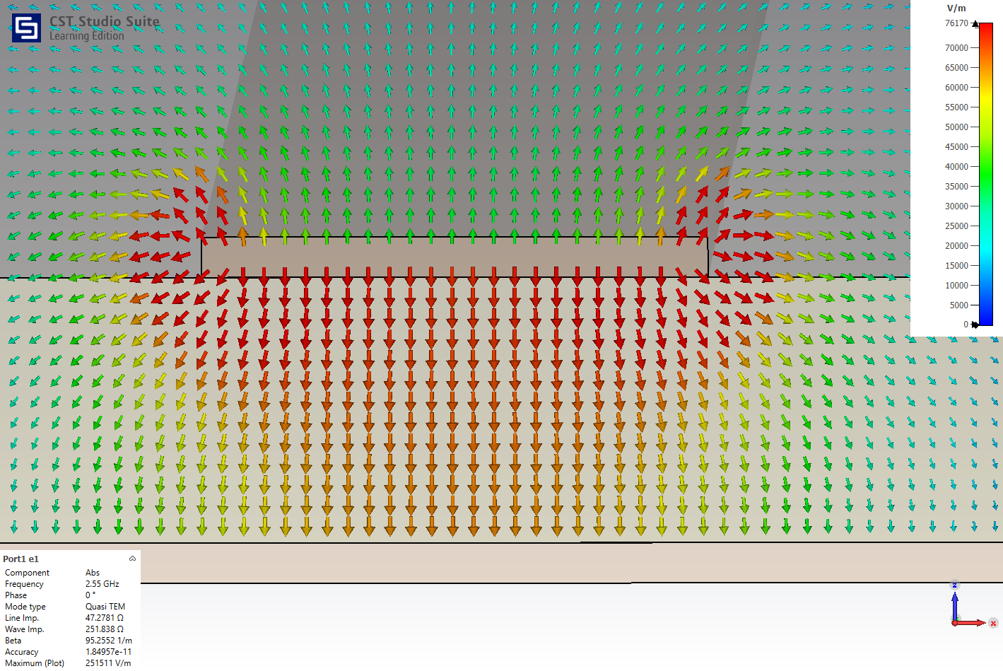
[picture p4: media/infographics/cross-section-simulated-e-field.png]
    
    <figcaption><i>Cross-section of the microstrip. CST simulation of <b>E</b>-field.</i></figcaption>
    </center>
  </figure>
</details>
<br />

#### 1.3.1 Intuitive Picture

<div class="quote feynman">
  You might think the magnetic field comes from the current in the copper — and that’s true, but only part of the story.

  Between the trace and the return plane, there’s no current flowing in the usual sense. But the electric field there is changing as the signal moves. And a changing electric field produces a magnetic field just as surely as a current does.

  So the magnetic field doesn’t start and stop at the copper. It wraps around the trace, passes through the dielectric, and closes on itself as a continuous structure.

  The current in the copper and the changing field in the dielectric are just two ways of sustaining the same magnetic field.

  If you tried to remove the displacement current term, the field would have nowhere to go — it would break at the boundary. Maxwell added that term so the field could remain whole.
</div>
<br />

#### 1.3.2 Sources of the Magnetic Field

The magnetic field is governed by the Ampère–Maxwell equation:
<div class="quote">

$$
    \nabla \times \mathbf B =
    \mu \, \mathbf J 
    \;+\;
    \mu\,\varepsilon\, \frac{\partial \mathbf E}{\partial t}
    \tag{Ampère–Maxwell}
$$
</div>

This identifies two sources:
- **conduction current $\mathbf J$**
- **displacement current $\varepsilon\frac{\partial\mathbf{E}}{\partial t}$**
<br />

#### 1.3.3 Region-Dependent Contributions

In different regions different terms dominate:

In the **conductor** (§1.2)[^k2j]:
- $\mathbf E \approx 0$ inside
- displacement current is negligible
- magnetic field is sustained by **conduction current $\mathbf J$**

In the **dielectric** (§1.1):
- $\mathbf J = 0$
- magnetic field is sustained by the **displacement current $\varepsilon\frac{\partial\mathbf{E}}{\partial t}$**

Inside a good conductor, both $\mathbf B$ and $\mathbf J$ decay together over the skin depth — most of the magnetic field of interest lives in the dielectric, with the surface current $\mathbf K$ matching the tangential $\mathbf B$ just outside (§1.2.4 boundary condition).

[^k2j]: The surface current $\mathbf K$ from §1.2 is just $\mathbf J$ integrated across the skin-depth layer where the current flows.
<br />

#### 1.3.4 Continuity Across the Interface

The governing equation is valid everywhere; only the dominant source term changes between regions.

The magnetic field forms a single continuous solution across the structure, even though:
- it is supported by conduction current in the conductor
- it is supported by displacement current in the dielectric

At the boundary, the tangential magnetic field is consistent with the required surface current. Without the displacement current term, $\nabla \times \mathbf B$ would have a jump at the dielectric boundary — Maxwell added that term precisely so the field could remain whole, as §1.3.1 put it.

**Closed current loop.** The continuity of the field is mirrored by a continuity of the *current* itself. Conduction current in the trace, displacement current in the dielectric, and conduction current in the return plane form one closed loop, required by the divergence-free constraint $\nabla \cdot \left(\mathbf J + \varepsilon\,\partial \mathbf E/\partial t \right) = 0$:

- forward in the trace (along $+\hat z$)
- across the dielectric in $+\hat x$ at the leading edge of a positive pulse (as $\mathbf E$ grows)
- back in the return plane (along $-\hat z$)
- across the dielectric in $-\hat x$ at the trailing edge (as $\mathbf E$ decays)

The trace and the return plane act like the plates of a propagating capacitor: conduction in the metal, displacement in the dielectric, conduction back. The two source terms are not parallel mechanisms — they are complementary segments of one continuous current loop.
<br />

#### 1.3.5 Interpretation

The magnetic field lives primarily in the dielectric, with a thin skin-depth penetration into the conductors — a single continuous field across the structure. Conduction current and displacement current are not separate phenomena; they are two contributions to the same electromagnetic field.

**Reconciling §1.2 and §1.3** 

§1.2 said "$\mathbf B$ determines $\mathbf K$"; §1.3 says "$\mathbf J$ sustains $\mathbf B$." These are not in conflict, and together they are the formal resolution of §1.3.1's "only part of the story." Maxwell-Ampère, $\nabla \times \mathbf B = \mu \mathbf J + \mu\varepsilon\,\partial \mathbf E/\partial t$, is an *identity* relating $\mathbf B$, $\mathbf J$, and $\partial \mathbf E/\partial t$ at every instant — none of the three is "the cause" of the others. The causal story is the one from §1.2: the wave in the dielectric is primary, and it drives the surface currents. Once those currents exist, Maxwell-Ampère bookkeeping requires them (together with the displacement current) to source the same continuous $\mathbf B$ field that drove them in the first place.

For design, the closed-loop view is the one that matters. The loop's geometry sets its inductance — that's what §1.4 turns into a design lever (rail collapse, decoupling, stack-up). Break the conduction return (a slot in the plane, a missing return via) or break the displacement-current path (an abrupt change in dielectric) and the loop opens up — the fields stop cancelling at a distance, and the failure modes of §1.5 (crosstalk) and §1.6 (EMI) follow directly.
<br />

#### 1.3.6 Summary

The magnetic field around a PCB trace is sustained by conduction current in the conductors and displacement current in the dielectric — together forming a single closed loop. Both terms are required by Maxwell's equations; neither alone is sufficient.
<br />

---

<br />

### 1.4 Power Distribution Network and Rail Collapse

The power distribution network (PDN) supplies the electromagnetic energy that active devices need to support changing current and voltage.

> **The central question: when a chip switches, where does the energy come from, and why isn't it always there in time?**
<br />

#### 1.4.1 Intuitive Picture

<div class="quote feynman">
  You ask the circuit for current right now.

  But current isn’t just charge moving — it’s a magnetic field wrapped around a path. And that field has to grow if the current grows. The bigger the path, the more field there is to grow — geometry matters.

  Growing a magnetic field takes energy, and it takes time. The supply can’t instantly reshape the field everywhere in the power network — the news has to travel from the chip to the supply and back, at the speed of light in the dielectric. Fast, but for sub-nanosecond logic, still not fast enough.

  So what happens? The device pulls what it can locally, and the voltage dips. That’s rail collapse.

  The decoupling capacitor is sitting right there with energy already stored in its electric field. It doesn’t need to wait. It hands over the charge immediately while the rest of the system catches up.

  The whole event is a negotiation between electric and magnetic fields trying to reconfigure themselves fast enough to meet the demand.
</div>
<br />

#### 1.4.2 Voltage Drop and Inductance

When a device switches, it requires a rapid increase in current. This corresponds to an increase in the magnetic field surrounding the current loop, with energy
$$
  W_L = \tfrac{1}{2} \, L \, I^2
$$
where $L$ is the inductance of the loop. Increasing current requires increasing this stored magnetic energy, and that energy has to be delivered through the PDN. The cost is a voltage drop:
<div class="quote">

$$
  \Delta V = L \, \frac{dI}{dt}
$$
</div>

If the voltage drop is large enough — what designers call **rail collapse** — the chip misinterprets logic levels or produces timing errors.
<br />

#### 1.4.3 Field Interpretation

The circuit relation $\Delta V = L\,dI/dt$ is the macroscopic shadow of a field-level event. The chip's switching current flows in a loop — out the supply pin, through the bond wires, package leads, PCB power and ground planes, and back. That loop has a magnetic field threaded through it, with energy density $\tfrac{1}{2}\mathbf B^2/\mu$ stored throughout the volume the field occupies — primarily inside the loop.

When the chip demands more current, the $\mathbf B$ field everywhere in that loop must grow. Two field-level constraints make this hard:

- **Energy delivery is wave-rate-limited.** The energy has to travel from the supply to the chip, and the supply only "knows" about the demand once it reaches it. Both legs are bounded by the speed of light in the dielectric ($\approx 16$ cm/ns in FR-4) — a 5 cm path adds $\approx 310$ ps each way, comparable to the rise time of fast logic.
- **A growing $\mathbf B$ field induces an opposing $\mathbf E$ field** (Faraday). This back-EMF appears as a voltage drop across the loop's inductance and subtracts from the rail at the chip pin.

The decoupling capacitor sidesteps both. Its electric field already stores energy locally — $W_C = \tfrac{1}{2}\,C\,V^2$, in the dielectric between its plates, millimeters from the load. The cap doesn't need to grow a $\mathbf B$ field across a long loop; it just releases stored $\mathbf E$-field energy through a much shorter path. The smaller the loop from cap to load, the smaller its inductance, and the less back-EMF the demand produces.

This swap — the cap's $\mathbf E$-field reservoir feeding the growing $\mathbf B$-field around the demand loop — is the "negotiation between electric and magnetic fields" the §1.4.1 intuition named. Every time the chip switches, an $\mathbf E$-field somewhere has to give up energy so a $\mathbf B$-field somewhere can grow.

Rail collapse is therefore the price the chip pays for these two constraints. The design levers that fight back are **minimize loop inductance** and **shorten the distance to local energy reservoirs**.
<br />

#### 1.4.4 Example

A typical microcontroller might switch 100 mA in 1 ns. A 5 mm trace between a poorly placed decoupling capacitor and the chip presents about $L = 5\,\text{nH}$ of parasitic inductance:
$$
  \Delta V = 5\,\text{nH} \cdot \frac{100\,\text{mA}}{1\,\text{ns}} = 500\,\text{mV}.
$$

A 500 mV dip on a 3.3 V rail is enough to upset logic levels on most chips. The lever is brutally simple: shorten the path.
<br />

#### 1.4.5 Summary

Rail collapse is the gap between how fast a chip's current loop demands $\mathbf B$-field energy and how fast the supply can deliver it. The two design levers — both turned into concrete rules in §2.1 — are minimizing loop inductance (tight power/return coupling, short via paths, continuous return planes) and placing local $\mathbf E$-field reservoirs (decoupling capacitors) close enough to the load that the speed-of-light round-trip stays under the chip's rise time.
<br />

---

<br />

### 1.5 Crosstalk

Crosstalk is interaction between electromagnetic fields associated with different conductors.

> **The central question: how does a signal on one trace end up on a neighboring trace that no wire connects it to?**
<br />

#### 1.5.1 Intuitive Picture

<div class="quote feynman">

Look. Two traces on a board, side by side. One of them is doing something — call it the *aggressor*, that's the standard name. The other is just sitting there, minding its own business. Call it the *victim*. Because in a moment, that's what it is.

Here's the trouble. When you draw the aggressor on your schematic, you picture its field as a neat little package tucked between the trace and the return plane underneath. But fields don't care about your schematic. Maxwell tells them where to go, and Maxwell says fields *spread*. Most of the energy stays where you want it, sure — but some of the electric field bulges sideways into the dielectric, and some of the magnetic loops swing out wider than the trace itself. The fields are leaky. They don't have to be. They just are.

And the victim is sitting right there in the leak. It didn't ask to be. The field doesn't ask permission.

When the aggressor's *voltage* swings, the electric field changes everywhere — including over the victim. And what does a changing electric field do to a piece of metal? It pushes charge around. So charge moves on the victim. That's **capacitive coupling**. The two traces, whether you wanted it or not, *are* a capacitor.

When the aggressor's *current* swings, the magnetic field changes everywhere — including through the little loop the victim makes with its own return path. And what does a changing magnetic field do to a loop? It drives a current around it, in the direction that *opposes the change* — Lenz's law, nature being stubborn about being pushed around. That's **inductive coupling**. The two trace-loops, whether you wanted it or not, *are* a transformer.

So far, both effects just add up. But here's the puzzle: they don't add up the same way at both ends of the victim.

The capacitive current splits and travels *both* ways down the victim. The inductive current, because of Lenz, flows only *one* way — backward, toward the aggressor's source.

So at the near end (the end nearest the source), both effects push the same way and they *reinforce*. **Near-end crosstalk** — substantial. At the far end, they push opposite ways and they *fight*. **Far-end crosstalk** — on a uniform line, almost cancels. Same physics. Opposite sign. Depends on which end you put your probe.

And once you see it, crosstalk stops looking like two circuits sneaking signals at each other. It's *one* electromagnetic field sloshing around between the aggressor and its return — and a second piece of copper that, through no fault of its own, found itself sitting where the field happens to be. Move the copper. Or confine the field. The fields never cared about your circuits to begin with.
</div>
<br />

#### 1.5.2 Geometry and Field Overlap

Consider two parallel microstrip traces above a common return plane:
- the **aggressor** trace carries a time-varying signal
- the **victim** trace is initially quiet

As a voltage step propagates along the aggressor, it generates:
- an electric field $\mathbf E$ between trace and return plane
- a magnetic field $\mathbf B$ looping around the trace

These fields are not perfectly confined to the region directly beneath the aggressor. A portion extends laterally into the surrounding dielectric. If the victim trace lies within this region, it is exposed to both fields. Each produces a different coupling mechanism — and both are direct consequences of Maxwell's equations.

<figure>
  <center>
  
  <figcaption><i>Cross-section: Capacitive coupling (<b>E</b> field fringing between traces) and inductive coupling (<b>B</b> field threading the victim loop).</i></figcaption>
  </center>
</figure>
<br />

#### 1.5.3 Capacitive Coupling (electric field)

The electric field terminates partly on the neighboring conductor, creating **mutual capacitance**.

<details>
  <summary>Expand if you ❤️ to see the derivation.</summary>

  Imagine two parallel traces on a PCB:
  - Trace 1 (Aggressor): has a time-varying voltage $V(t)$
  - Trace 2 (Victim): is affected by the electric field of Trace 1
  - $C_m$ (Mutual Capacitance): the capacitance between Trace 1 and Trace 2

By definition, the charge $Q$ induced on the victim trace due to the potential on the aggressor trace is proportional to the mutual capacitance: 
<div class="quote">

  $$
    Q = C_{m}\cdot V_{1}
  $$
</div>

From the Continuity Equation ($\nabla \cdot \mathbf{J} + \frac{\partial \rho}{\partial t} = 0$), we know that a change in charge over time results in a flow of current. Taking the time derivative of the charge equation:
$$
  \frac{dQ}{dt} = \frac{d}{dt}(C_m V_1)
$$

The current $I$ is defined as the rate of flow of charge ($I = dQ/dt$). Since $C_m$ is set by the trace geometry (constant), it pulls out of the derivative, leaving:
$$
  I_C = C_m \, \frac{dV}{dt}
$$
The capacitive coupling current on the victim is proportional to $dV/dt$ on the aggressor.
</details>

<div class="important-note"><span class="icon">💡</span>

A time-varying voltage on the aggressor produces a time-varying electric field. This induces surface charge on the victim trace, resulting in current:
$$
    I_C = C_m \ \frac{dV}{dt}
$$ where:
- $I_C$ is the current in the victim trace
- $C_m$ is the mutual capacitance
- $V$ is the voltage on the aggressor
</div>

Characteristics:
- proportional to the voltage transition rate $dV/dt$
- depends on the strength and spatial extent of the electric field
- increases with closer spacing, longer parallel runs and weaker field confinement
<br />

#### 1.5.4 Inductive Coupling (magnetic field)

The changing current in the aggressor generates a changing magnetic field. Part of this field links the loop formed by the victim trace.

<details>
  <summary>Expand if you ❤️ to see the derivation.</summary>

  By Faraday’s law, the changing magnetic flux induces an electric field:
  $$
      \nabla \times \mathbf{E} = -\frac{\partial \mathbf{B}}{\partial t} 
      \tag{\text{Faraday}}
  $$

  Integrate Faraday's law over the open surface $S$ of the victim loop:
  $$
    \iint_S (\nabla \times \mathbf{E}) \cdot d\mathbf{a} = -\iint_S \frac{\partial \mathbf{B}}{\partial t} \cdot d\mathbf{a}
  $$

  Using Stoke's Theorem, we convert the surface integral of the curl of $\mathbf E$ into a line integral of $\mathbf E$ around the closed boundary loop $C$.
  $$
    \oint_C \mathbf{E} \cdot d\mathbf{l} 
    = - \frac{d}{dt} \iint_S \mathbf{B} \cdot d\mathbf{a}
  $$

  The term on the left, $\oint_C \mathbf{E} \cdot d\mathbf{l}$, is the definition of electromotive force or **induced voltage** $V_{ind}$.

  The surface integral on the right is the definition of magnetic flux ($\Phi_m$) passing through the loop:
  <div class="quote">

  $$
    \Phi_m = \iint_S \mathbf{B} \cdot d\mathbf{a}
  $$
  </div>

  This simplifies the relationship to:
  $$
    V_L = - \frac{d\Phi_m}{dt}
  $$

  The magnetic flux ($\Phi_m$) threading through the victim loop is physically created by the current $I$ in the aggressor loop. Because the relationship is linear for most materials, we define **Mutual Inductance ($L_m$)** as the ratio of flux to current.
  $$
    \Phi_m \triangleq L_m I
  $$ where $L_m$ "hides" the geometry (distance, height and length) into a single constant.

  Finally, we substitute the definition of flux back into the Faraday result
  $$
    \begin{align*}
    V_L &= - \frac{d(L_m I )}{dt} \\
    &= - L_m\,\frac{d I}{dt}
    \end{align*}
  $$
</details>
<br />

<div class="important-note"><span class="icon">💡</span>

The changing magnetic flux creates an induced field that opposes the change that created it. The induced voltage:  
$$
  V_L = - L_m\frac{dI}{dt}
$$ where:
- $V_L$ is the induced voltage on the victim trace
- $L_m$ is the mutual inductance between the two trace-return-plane loops
- $I$ is the current in the aggressor trace
</div>

 It depends on how much of the aggressor's $\mathbf B$ field threads through the victim's loop — set by the physical distance between traces, the height above the return plane, and the length of the parallel run.

Characteristics:
- proportional to the rate of change of the aggressor's current $dI/dt$
- depends on loop geometry and magnetic flux linkage
- increases with larger loop area and weaker return-path control
<br />

#### 1.5.5 Combined Effect

This is the reinforce-vs-fight asymmetry that the §1.5.1 intuition foreshadowed. Formally:

The capacitive and inductive coupled signals arrive at the victim differently:

- **Capacitive coupling** injects current into the victim trace. That current splits and travels in both directions — toward the near end and the far end. Both ends see a pulse of the same polarity as the aggressor.

- **Inductive coupling** induces a current that opposes the aggressor's current (Lenz's law). That current flows toward the near end, producing a pulse of the same polarity as the aggressor there, and a pulse of opposite polarity at the far end.

The total induced signal is the sum of capacitive and inductive contributions.

In uniform transmission lines:

- **Near-End Crosstalk (NEXT)** appears closest to the aggressor's source. The capacitive and inductive components have the same polarity — they reinforce.

- **Far-End Crosstalk (FEXT)** appears at the far end. The capacitive and inductive components have opposite polarity — they partially cancel.
<br />

#### 1.5.6 Design Implications

Crosstalk depends on field overlap and geometry:
- **Trace spacing:** increasing separation reduces field overlap
- **Dielectric thickness:** reducing height to the return plane improves confinement
- **Return path continuity:** uninterrupted reference planes prevent field spreading
- **Aggressor loop area:** smaller loop generates less $\mathbf B$ field
- **Victim loop area:** smaller loop captures less flux
<br />

#### 1.5.7 Summary

Crosstalk is the result of electromagnetic fields from one conductor interacting with another. It arises from:
- electric-field coupling (mutual capacitance)
- magnetic-field coupling (mutual inductance)

Both are direct consequences of Maxwell’s equations. As §1.5.1 put it: there is one shared electromagnetic field, and the victim is a conductor that found itself in the wrong place. Every layout decision that follows in §2 either reduces the field's reach or reduces the victim's overlap with it.
<br />

---

<br />

### 1.6 Electromagnetic Interference (EMI)

Signal integrity asks whether the field arrives at the receiver correctly; EMI asks whether the field arrives somewhere it should not.

> **The central question: when the field escapes the intended region between trace and return plane, where does it go?**
<br />

#### 1.6.1 Intuitive Picture

<div class="quote feynman">
  Here's a thing about your PCB trace that nobody tells you. It is, secretly, an antenna. It always was.

  Because what's a trace, really? A piece of metal carrying a current. And what's an antenna? A piece of metal carrying a current. The difference between the two is whether the field stays put.

  When you do everything right — trace tight to its return plane, return path continuous, loop area small — the field *does* stay put. The forward-going field around the trace and the backward-going field around the return current cancel each other out at any reasonable distance. A meter from the board, it's like the trace isn't even there. The wave runs happily down the line, the receiver is happy, and nothing leaks.

  But break the containment — *anywhere* — and the cancellation fails. A slot in the return plane. A long via transition without a return via. Power and ground too far apart. Whatever it is, the return current can't stay underneath the signal. It detours. The loop opens up. The forward and backward fields no longer have anyone to cancel against.

  And what do unconfined fields do? They don't sit around politely. They propagate. They've always wanted to propagate — that's what fields do — and now nothing's holding them in. The wave that was supposed to travel from your driver to your receiver is *also* traveling sideways, outward, into your enclosure, into the air, into the next room. At the speed of light. In every direction. And the bigger the loop you accidentally opened up, the more of the wave is getting out.

  Here's the scary part. The radiated power scales as the *square* of the loop area, and the *fourth* power of frequency. Double the frequency: sixteen times more radiation. Quadruple the loop area: another sixteen times. Both at once: 256 times. That's why this hurts more every year — switching speeds keep going up, and the physics doesn't.

  And once you see this, EMI stops looking like a separate failure mode. It's crosstalk where the victim is *very far away*. Same loose fields. Same Maxwell. Same return-path discipline. You're either keeping the field where you put it, or you're not. And if you're not, sooner or later the field is going to find somebody it doesn't belong to.
</div>

#### 1.6.2 Field Confinement

To make the intuition above precise: in a well-designed structure, the signal's electric and magnetic fields stay tightly localized between the trace and its return plane. The forward field around the trace and the backward field around the return current cancel at any reasonable distance — the structure looks neutral from outside, even though it carries significant power inside.

Three geometric conditions deliver this confinement:
- a continuous reference plane directly under the signal layer
- minimal trace-to-plane distance, so the field is squeezed into a small dielectric volume
- minimal loop area, set by the area enclosed between the forward signal current and its return current

The continuous return plane is the load-bearing element. It allows the return current to localize directly under the signal, which is what keeps the loop small. When all three conditions are met, little energy escapes, coupling to other conductors is minimal, and radiation is weak.
<br />

#### 1.6.3 Loss of Confinement

When the geometry conditions of §1.6.2 are violated, the fields must expand to satisfy Maxwell's equations. Common causes:
- gaps or splits in reference planes
- changes of reference layer without a close return via
- long via transitions that separate signal and return
- large separation between power and ground conductors

In each case, the return current cannot remain directly under the signal. It detours; the loop opens up; the forward and backward fields no longer have anyone to cancel against. The magnetic field spreads outward, and the electric field extends further into the surrounding space.

This expansion has two visible consequences. The **electric-field expansion** increases capacitive coupling to nearby conductors — felt by neighbors close enough to be in the bulging $\mathbf E$ field. The **magnetic-field expansion** increases mutual inductance with nearby loops, and at a distance becomes radiation into free space. Crosstalk and EMI are therefore the same failure mode at different ranges: both result from a loop that opened up further than the design intended.
<br />

#### 1.6.4 Radiation

The expanded loop is an antenna.

<div class="important-note"><span class="icon">💡</span>

For a small loop (perimeter ≪ $\lambda$), the radiated electric field magnitude $|\mathbf E_{rad}|$ scales as[^EMCLOOP]
$$
    |\mathbf E_{rad}| \;\propto\; \frac{f^2 \, A \, I}{r}
$$ where:
- $f$ is the frequency of the signal
- $A$ is the loop area
- $I$ is the loop current
- $r$ is the distance
</div>

[^EMCLOOP]: Derived from the magnetic dipole radiation formula. The full expression includes constants ($\mu_0$, $c$), but the proportionality to $f^2$, $A$, and $I$ captures the design levers.

The scaling is sharp. Radiated *power* goes as $f^4 A^2$ — doubling the frequency multiplies power by 16, and quadrupling the loop area another 16. This is why edge rates and unintended loop area dominate EMC budgets at modern switching speeds.
<br />

#### 1.6.5 Summary

EMI arises when electromagnetic fields extend beyond their intended region. Field confinement depends on a continuous, nearby return path and a small loop area. When the loop opens — from a plane discontinuity, a stray via, or a sloppy stack-up — the fields expand. At short range, the expansion shows up as crosstalk; at long range, as radiated emission. Controlling the geometry of the return path is the primary lever for both — the concrete layout rules are in §2.1.
<br />

---

---

<br />

## 2 From Physics to Layout

Everything in §1 reduces to one design reality:

> **A PCB layout defines the geometry of an electromagnetic wave.**

The trace and return plane form a guiding structure. The dielectric carries the energy. The conductors enforce boundary conditions that confine and shape the fields.

When this structure is preserved, signals propagate cleanly.
When it is disturbed, one or more of four failure modes appears:
- **Signal integrity** → wave disruption (reflections, ringing)
- **PDN failure** → insufficient energy delivery (rail collapse)
- **Crosstalk** → field overlap between structures
- **EMI** → loss of field confinement and radiation

The rules in §2.1 prevent these failure modes by controlling the **geometry of the electromagnetic field**. Sections §2.2–§2.7 then apply those rules to the OPNhydro PCB.
<br />

---

<br />

### 2.1 PCB Design Rules

The rules are organized by failure mode, mirroring chapter 1: signal quality (§2.1.1), power distribution (§2.1.2), crosstalk (§2.1.3), and radiated EMI (§2.1.4). Each rule is lettered within its subsection (Rule 1a, 1b, …) so the project-specific sections in §2.2–§2.7 can reference them precisely. §2.1.5 cross-tabulates the rules by the design aspect they control.
<br />

#### 2.1.1 Signal Quality

A signal traveling along a trace is an EM wave guided by the trace and its return plane. Anything that disrupts the wave's propagation — an impedance discontinuity, a missing return path, a stub — causes part of the energy to reflect back toward the source. The reflected wave interferes with the forward wave, producing ringing, overshoot, and timing uncertainty on the net.

**Rule 1a — Maintain a continuous return plane.** The $\mathbf B$ field from the forward current in the trace and the return current in the plane cancel at a distance, keeping the energy confined. A continuous plane provides a nearby, low-impedance return path, so the current loop is small and the fields close tightly around the trace. Interrupt the plane — a slot, a cutout, a missing pour — and the return current detours, the loop area grows, the impedance changes, and the wave partially reflects.

<figure>
  <center>
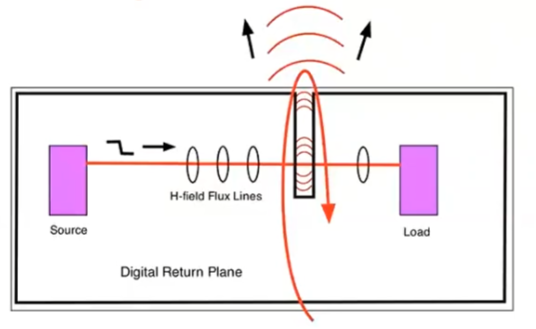
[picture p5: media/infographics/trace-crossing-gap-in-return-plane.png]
  
  <figcaption><i>Trace crossing a gap in the return plane.<br />(Courtesy: Kenneth Wyatt)</i></figcaption>
  </center>
</figure>

> "Forget the word ground. Every signal has a return path. Think return path and you will train your intuition to look for and treat the return path as carefully as you treat the signal path." -- Eric Bogatin

**Rule 1b — Provide return vias at layer transitions.** When a trace passes through a via, the EM wave transfers between layers. The wave is not just the trace — it is the field between the trace and its reference plane. If the return plane changes (say, from L2 to L3), the return current must also transition. Without a nearby ground via, the return path detours, the loop area grows, and the wave leaks between the return planes — causing both reflections on the signal net and interference with other signals in that space.

<figure>
  <center>
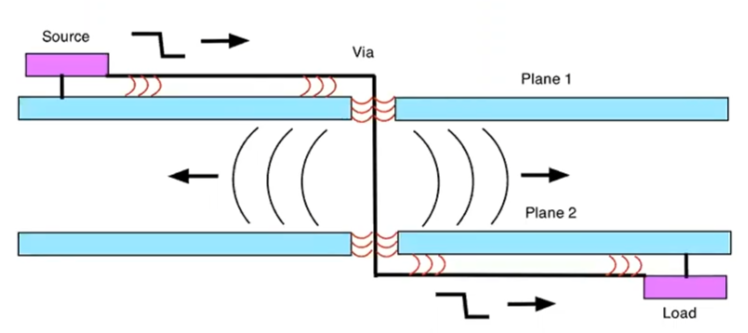
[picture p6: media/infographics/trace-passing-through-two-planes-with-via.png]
  
  <figcaption><i>Trace passing through two planes with via.<br />(Courtesy: Kenneth Wyatt)</i></figcaption>
  </center>
</figure>

If the planes are the same potential, prevent leakage with nearby stitching vias between them. If they are different potentials, place stitching capacitors as close to the signal via as possible.

**Rule 1c — Keep every signal and power layer one dielectric away from a return plane.** The wave's confinement weakens as the trace moves away from its return — fields spread laterally, the loop area grows, and the characteristic impedance becomes ill-defined. Every routing layer needs a return plane in the immediately adjacent dielectric (no skipping a layer). This constraint is what drives the stack-up choice in §2.2.
<br />

#### 2.1.2 Power Distribution

Every time a chip switches, it draws a sharp current pulse from the power rail. That pulse passes through the inductance of the power distribution network, producing a voltage drop $\Delta V = L_{\text{PDN}} \times \frac{dI}{dt}$. The goal is to minimize the PDN inductance across the full frequency range over which the chip draws current. Three levers reduce that inductance: tight coupling between power and return planes (small loop area), local energy reservoirs (decoupling caps close to the load), and continuous return paths (no detours that enlarge the loop).

**Rule 2a — Tightly couple power and return planes.** A power plane and return plane separated by a thin dielectric (2–3 mil) form a parallel-plate capacitor with very low inductance. This provides broadband decoupling across the entire board area — the EM field between the planes can supply current before the discrete capacitors or the regulator can respond. This design uses two GND planes (L2, L3) with power routed as traces rather than a dedicated plane, so broadband plane decoupling is achieved through discrete capacitors instead (see §2.2).

**Rule 2b — Use multiple, low-inductance decoupling capacitors.** A single capacitor has parasitic lead and via inductance that limits its effectiveness above its self-resonant frequency. Multiple smaller capacitors in parallel reduce the effective inductance (inductances in parallel divide). Place them as close to the chip's power pins as physically possible — every millimeter of trace adds inductance.

**Rule 2c — Minimize power and ground lead length in packages.** The inductance of the bond wires and package leads between die and PCB is often the dominant contributor to $L_{\text{PDN}}$ at high frequencies. Packages with multiple, short power and ground pins (QFN, BGA) have lower inductance than those with long leads (SOIC, DIP).

**Rule 2d — Rely on on-chip decoupling for the highest frequencies.** Every external capacitor has a self-resonant frequency $f_{\text{SRF}} \approx 1/(2\pi\sqrt{L_{\text{path}}\,C})$ set by the cap-via-trace path inductance and the cap value; above it, the cap looks inductive and stops decoupling. For typical PCB geometries this lands in the 50–200 MHz range — above that, no external capacitor can respond fast enough. Modern ICs include on-die decoupling for this regime. The PCB designer's job is to keep $L_{\text{PDN}}$ low at the frequencies *below* $f_{\text{SRF}}$.
<br />

#### 2.1.3 Crosstalk

Both coupling mechanisms — capacitive ($C_m$, from overlapping $\mathbf E$ fields) and inductive ($L_m$, from overlapping $\mathbf B$ fields) — depend on how much of the aggressor's field volume overlaps with the victim's. Every mitigation strategy reduces that overlap.

**Rule 3a — Increase trace spacing.** Both the fringing $\mathbf E$ field and the $\mathbf B$ field around a trace fall off rapidly with lateral distance — faster than $1/d$ once the spacing exceeds the trace-to-plane height, because the trace and its image current in the return plane act as an opposing pair whose fields cancel at distance. The 3W rule (center-to-center spacing of at least 3× the trace width) is the practical approximation: at $d = 3W$, coupling is roughly 1% of the $d = W$ case. For critical traces (analog sensors, clocks), use $5W$.

**Rule 3b — Minimize parallel run length.** Both $C_m$ and $L_m$ are proportional to the length over which two traces run in parallel. The coupling is cumulative — every millimeter of shared dielectric adds to the total. Where two sensitive traces must be routed near each other, cross them at 90° rather than running them in parallel.

**Rule 3c — Reduce trace height above the return plane.** The closer a trace is to its return plane, the more tightly the $\mathbf E$ and $\mathbf B$ fields are confined directly underneath. Less field energy spills sideways into the neighboring trace's volume.

**Rule 3d — Interpose a return plane between signal layers.** A grounded conductor between two signal layers terminates $\mathbf E$ field lines from traces above (Gauss's law — the lines land on the return plane instead of reaching the layer below) and provides a local return path that contains the $\mathbf B$ field, blocking inter-layer coupling.

**Rule 3e — Separate functional domains.** Motor control traces and analog sensor traces must not share the same dielectric space. Keep traces on adjacent layers perpendicular to each other to minimize the parallel run length between layers.
<br />

#### 2.1.4 EMI

EMI is not a separate problem — it is the consequence of every other problem listed above. When a return path is broken, the $\mathbf B$ fields stop cancelling and the loop radiates. When crosstalk couples energy onto an unintended trace, that trace becomes an unintentional antenna. When a rail collapses, the transient current loop radiates at the switching frequency and its harmonics.

**Rule 4a — Minimize loop area.** Every current — signal, power, return — forms a loop. For a given loop current $I$, the radiated power is proportional to the loop area squared and the fourth power of frequency: $P_{\text{rad}} \propto A^2 f^4 I^2$ (consistent with §1.6.4's $|\mathbf E_{rad}| \propto f^2 A I / r$). The chip and supply set $I$; layout sets $A$. Keep traces close to their return planes. Use ground vias at every layer transition. Route power close to its return.

**Rule 4b — Contain the fields at board edges.** EM fields that reach the edge of the PCB can radiate freely — there is no conductor to confine them. Pull traces and pours back from the board edge by at least 20× the dielectric thickness (the 20H rule). Place return plane stitching vias along the board perimeter to create a continuous shield.

**Rule 4c — Filter at I/O boundaries.** Every cable attached to the board is a potential antenna. Place filtering (ferrite beads, capacitors, common-mode chokes) at the point where signals enter or leave the board, before the field has a chance to propagate onto the cable.
<br />

#### 2.1.5 Summary

All PCB design rules reduce to controlling a few aspects of the electromagnetic field:
- **Continuity** → closed current loops (Rules 1a, 1b)
- **Confinement** → fields stay between trace and return (Rules 1c, 3c, 3d, 4a)
- **Separation** → minimal unintended coupling (Rules 3a, 3b, 3e)
- **Energy delivery** → local reservoirs near the load (Rules 2a–2d)
- **Containment at boundaries** → no escape into cables or air (Rules 4b, 4c)

A good PCB layout is one where the electromagnetic field has nowhere unexpected to go.
<br />

---

<br />

### 2.2 PCB Stack-up

The PCB has two hard constraints that drive most of the other design decisions. First, the 6.5 A peak current on the 24 V input rail requires copper heavy enough to handle that current without excessive resistive heating. Second, the isolation moats around the pH and EC islands must be maintained through all four layers, which means the layer stack-up cannot be an afterthought.

The **typical 4-layer stack-up** is SIG/GND/PWR/SIG. This design does not use it for two reasons. First, the power and return planes would be separated by the full core distance — too far apart for effective high-frequency decoupling (2–3 mil max is needed). Second, signals on Layer 4 would be referenced to the power plane rather than GND, which only works if the power and return planes are tightly coupled with adequate decoupling capacitors.

Instead, we opt for the **Low EMI 4-layer stack-up** as shown below.

Layer | Name   | Function                         | Components
------|--------|----------------------------------|--------------------------
L1    | Top    | Sensitive signals / routed power | ESP32, LiDAR, I2C, UART, EZO, BNC, 3V3/5V power traces
L2    | GND    | Ground return plane              | Primary return reference for L1 signals
L3    | GND    | Ground return plane              | Primary return reference for L4 signals
L4    | Bottom | Noisy signals / routed 24V power | Stepper drivers, MOSFETs, 24V power traces

<figure>
  <center>
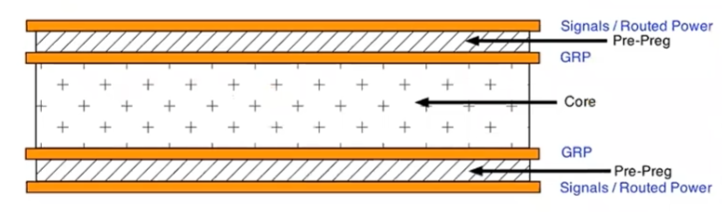
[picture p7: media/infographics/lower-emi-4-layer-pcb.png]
  
  <figcaption><i>Lower EMI in 4-layer PCB.<br />(Courtesy: Kenneth Wyatt)</i></figcaption>
  </center>
</figure>

<br />

---

<br />

### 2.3 PCB Materials

The design specifies a **4-layer PCB with 2 oz copper on the outer layers**. The heavier copper on L1 and L4 keeps resistance and heat low on the high-current 24V traces. The two inner layers (L2 and L3) use standard 1 oz copper, which is sufficient for the return planes they carry.

**PCB finish:** HASL (Hot Air Solder Leveling) is sufficient and lowest cost for the packages used in this design (SSOP-20 at 0.65 mm pitch and larger). ENIG (Electroless Nickel Immersion Gold) is only worth the premium if a future revision adds true fine-pitch parts (QFN/LGA at 0.5 mm or below, or BGA).

Note:
- JLC PCB
- Base material FR-4 TG135 ($\varepsilon_r\approx 4.4$ at 1 GHz)
- Layers 4
- Thickness 1.6mm
- Surface finish: HASL (with lead)
- Trace width for 50 Ohm impedance (single ended non coplaner) 6.16 mil 0.156 mm

Layer   | Material                  | Tickness  | Thickness
--------|---------------------------|-----------|----------
L1      | outer copper weight 1oz   |  1.38 mil | 0.0350 mm
Prepreg | 3313 RC57% 4.2mil         |  3.91 mil | 0.0994 mm
L2      | Inner copper weight 0.5oz |  0.60 mil | 0.0152 mm
Core    | 1.3mm H/HOZ with copper   | 49.80 mil | 1.2650 mm
L3      | Inner copper weight 0.5oz |  0.60 mil | 0.0152 mm
Prepreg | 3313 RC57% 4.2mil         |  3.91 mil | 0.0994 mm
L4      | outer copper weight 1oz   |  1.38 mil | 0.0350 mm

---

### 2.4 Segregating Functional Regions

The board layout separates functional domains to minimize coupling between noise sources and sensitive circuits:

- Keep the BNC-to-EZO analog links and the EZO-to-MCU serial lines away from motor control and digital switching sections.
- Place power conversion (buck converter) and motor control (TMC2209 drivers) near the power entry point, so high-current loops stay short.
- Filter and transient-protect all power and I/O connectors at the board boundary.
- Group all power and I/O connectors along one edge of the board where possible, to contain cable radiation (Rule 4c).

---

### 2.5 Enclosure and Mechanical

The board targets a ~100 mm × 80 mm footprint, which fits standard off-the-shelf enclosures. Recommended specifications:

- **Enclosure:** IP65-rated ABS, approximately 150 × 100 × 70 mm. The IP65 rating keeps moisture and insects out of the electronics.
- **Cable glands:** Use glands for every wire entering the enclosure — probe cables, pump leads, and the PSU input.
- **BNC connectors:** Mount three panel-mount BNC connectors on the enclosure face for the pH, EC, and RTD probes. Panel-mount rather than PCB-mount prevents mechanical stress on the isolation islands if a probe cable is tugged.
- **Optional:** A clear lid panel allows status LED visibility without opening the enclosure.

### 2.6 Trace Widths

The trace widths can be calculated using the IPC-2221 empirical formula for PCB conductors.[^1]
[^1]: [IPC-2221 Trace Width Calculator, Altium PCB Design Guide](https://resources.altium.com/p/ipc-2221-calculator-pcb-trace-current-and-heating).

$$
    \begin{align}
    I  &= k \times \Delta T^{0.44} \times A^{0.725} \\
    \rm{where\ \ } I &= \rm{current\ [A]} \nonumber \\
    k  &= 0.048 \rm{\ for\ outer\ layer,\ or\ } 0.024 \rm{\ for\ inner\ layer} \nonumber \\
    \Delta T &= \rm{allowable\ temperature\ increase\ [°C]} \nonumber \\
    A  &= \rm{cross\text{-}sectional\ area\ [mil²]} =  width_{mil} \times thickness_{mil} \nonumber \\
   thickness_{mil} &= 1.37 \rm{\ mil\ for\ 1oz\ Cu,\ or\ } 2.74 \rm{\ mil\ for\ 2oz\ Cu} \nonumber 
\end{align}
$$

The table below uses a conservative $\Delta T = 10^\circ\mathrm{C}$ (IPC-2221 permits 20°C for most PCB classes). The inner-layer widths assume 1 oz copper; the outer-layer widths assume 2 oz copper per §2.3. Power nets are routed on the outer layers in this stack-up (§2.2), so the inner-layer column is reference-only — a 200 mil inner trace at 1 oz carries only ~3.9 A, which is **not** sufficient for the 6.5 A peak on the 24 V input. If any power net must be routed internally, treat the external-column width as a floor and widen further to compensate for the 1 oz inner copper.

Net                     | Target Current    | Internal Trace Width | External Trace Width | Rationale
------------------------|-------------------|----------------------|----------------------|----------
24V input (PSU→TVS→RPP) | 6.5A (Peak)       | N/A†       |  2.0mm (80mil)       | Reduce sag
24V main pump           | 1.2A (Continuous) | 1.0mm  (40mil)       |  0.4mm (15mil)       | Manage heat
24V each dosing pump    | 1.53A (Peak)      | 1.0mm  (40mil)       |  0.4mm (15mil)       | Peak current headroom
24V ATO valve           | 0.3A (Peak)       | 0.2mm   (8mil)       |  0.2mm  (8mil)       | Fab minimum
5V rail (post-buck)     | 0.75A (Peak)      | 0.5mm  (20mil)       |  0.2mm  (8mil)       | Stable power
3.3V rail (post-LDO)    | 0.15A (Peak)      | 0.2mm   (8mil)       |  0.2mm  (8mil)       | Fab minimum

† Inner-layer routing cannot carry 6.5 A at 1 oz copper within any practical trace width. This net must remain on an outer layer.

### 2.7 PCB Layout Strategy

- **Star power distribution** — Run a dedicated pair of 24V traces from the power entry connector directly to the stepper section, and a separate pair to the logic regulator. Do not daisy-chain power from the motors to the sensors.
- **Via stitching for high-current transitions** — When the 24V rail transitions between layers, use at least 3–4 vias per 2A connection. A single standard 10 mil via carries only 0.5–1A before excessive heating.
- **Decoupling capacitor placement** — Place bulk capacitors (10–100 µF) within 10 mm of each power pin cluster. Place high-frequency bypass capacitors (100 nF ceramic) within 2 mm of the chip power pin they serve, with vias dropping straight to the return plane. Route the capacitor's return via before the signal via — current must flow through the capacitor, not around it (Rule 3b).
- **Isolation moat continuity** — The pH and EC islands require unbroken isolation moats through all four layers (§2.2). No trace, pour, or via may cross the moat except the designated serial links, which must bridge the gap with adequate creepage. Verify moat integrity in the fabrication output for every layer.
- **Board-edge clearance** — Pull all traces and copper pours back from the board edge by at least 20× the dielectric thickness (Rule 4b). On the OPNhydro stack-up, this is approximately 1.5 mm. Place return-plane stitching vias along the board perimeter at ≤5 mm intervals.
- **Antenna keep-out** — The return plane must not extend under the ESP32-C6 antenna keep-out area to ensure proper wireless performance.

<br />

---

<br />

## Appendix A: More Math for Curious Readers

### A.1 Ampère-Maxwell law Couples Time Variation of E to Spatial Variation of B

For the wavefront traveling in the $+\hat z$ direction, at a place in between the trace and the return plane, we can apply some simplifications:
1. The magnetic field does not vary along $x$ or $y$, so all $\partial/\partial x$ and $\partial/\partial y$ vanish.
2. The magnetic field points in the $\pm\hat y$-direction, so $B_x = B_z = 0$.

Since there is no current $\mathbf{J}$ in the dielectric, the law simplifies to:
$$
    \nabla \times \mathbf{B} 
    = \mu\, \varepsilon \frac{\partial \mathbf{E}}{\partial t}
$$

Expand the curl ($\nabla \times \mathbf B$) operator, do a Laplace expansion for the matrix determinant:
$$
  \begin{align*}
    \nabla \times \mathbf{B} 
    &= \mu\, \varepsilon \frac{\partial \mathbf{E}}{\partial t} \\
    \Rightarrow
    \begin{vmatrix}
      \hat x & \hat y & \hat z \\
      \frac{\partial}{\partial x} & \frac{\partial}{\partial y} & \frac{\partial}{\partial z} \\
      B_x & B_y & B_z
    \end{vmatrix} 
    &= \mu\, \varepsilon \frac{\partial \mathbf{E}}{\partial t} \\
    \Rightarrow
    \hat x
    \begin{vmatrix}
      \frac{\partial}{\partial y} & \frac{\partial}{\partial z} \\
      B_y & B_z
    \end{vmatrix}
    - \hat y
    \begin{vmatrix}
      \frac{\partial}{\partial x} & \frac{\partial}{\partial z} \\
      B_x & B_z
    \end{vmatrix}
    + \hat z
    \begin{vmatrix}
      \frac{\partial}{\partial x} & \frac{\partial}{\partial y} \\
      B_x & B_y
    \end{vmatrix}
    &= \mu\, \varepsilon \frac{\partial \mathbf{E}}{\partial t} \\
    \Rightarrow
    \left(\frac{\partial B_z}{\partial y} - \frac{\partial B_y}{\partial z}\right) \hat x
    - \left(\frac{\partial B_z}{\partial x} - \frac{\partial B_x}{\partial z}\right) \hat y       
    + \left(\frac{\partial B_y}{\partial x} - \frac{\partial B_x}{\partial y}\right) \hat z
    &= \mu\, \varepsilon \frac{\partial \mathbf{E}}{\partial t} \\
  \end{align*}
$$

From the assumptions, we know that the field strength only changes as the wave travels down the line → $\frac{\partial}{\partial x} = \frac{\partial}{\partial y} = 0$, and the magnetic field only exists in the $y$-direction → $B_x = B_z = 0$. Applying these assumptions cancels every term except one:
$$
  \begin{align*}
    \left( \bcancel{\frac{\partial B_z}{\partial y}} - \frac{\partial B_y}{\partial z} \right) \hat x
    - \left( \bcancel{\frac{\partial B_z}{\partial x}} - \frac{\partial \cancel{B_x}}{\partial z} \right) \hat y       
    + \left( \bcancel{\frac{\partial B_y}{\partial x}} - \bcancel{\frac{\partial B_x}{\partial y}} \right) \hat z
    &= \mu \, \varepsilon \frac{\partial \mathbf{E}}{\partial t} \\
    \Rightarrow \frac{\partial B_y}{\partial z} \, (-\hat x)
    &= \mu \, \varepsilon \frac{\partial \mathbf{E}}{\partial t}
  \end{align*}
$$

This implies that only the part of $\mathbf{E}$ in the $x$-direction is relevant.
$$
    \frac{\partial B_y}{\partial z} (-\hat x) = \mu \, \varepsilon \frac{\partial E_x}{\partial t}\, \hat x
$$

<div class="important-note"><span class="icon">💡</span>

The rate of change in the electric field **in time** ($t$) is exactly balanced by the rate of change of the magnetic field **in space** ($z$)
$$
  \frac{\partial B_y}{\partial z} = -\mu\, \varepsilon\, \frac{\partial E_x}{\partial t}
$$
</div>

So, if $\mathbf E$ is changing in time at some point, the Ampère-Maxwell equation forces $\mathbf B$ to have a spatial gradient there — so $\mathbf B$ at the neighboring point is different. At that neighboring point, $\mathbf B$ is now changing in time, and by the second equation this forces spatial variation in $\mathbf E$ — so $\mathbf E$ at the *next* point is different. And so on.

<br />

---

<br />

### A.2 Faraday's law Couples Time Variation of B to Spatial Variation of E

We can do the same for **Faraday's law**.

For the wavefront traveling in the $+\hat z$ direction, at a place in between the trace and the return plane, we can apply some simplifications:
1. The electric field does not vary along $x$ or $y$, so all $\partial/\partial x$ and $\partial/\partial y$ vanish.
2. The electric field points in the $\pm\hat x$-direction, so $E_y = E_z = 0$.

Expand the curl ($\nabla \times \mathbf E$) operator, do a Laplace expansion for the matrix determinant:
$$
  \begin{align*}
    \nabla \times \mathbf{E} 
    &= -\frac{\partial \mathbf{B}}{\partial t} \\
    \Rightarrow
    \begin{vmatrix}
      \hat x & \hat y & \hat z \\
      \frac{\partial}{\partial x} & \frac{\partial}{\partial y} & \frac{\partial}{\partial z} \\
      E_x & E_y & E_z
    \end{vmatrix} 
    &= -\frac{\partial \mathbf{B}}{\partial t} \\
    \Rightarrow
    \hat x
    \begin{vmatrix}
      \frac{\partial}{\partial y} & \frac{\partial}{\partial z} \\
      E_y & E_z
    \end{vmatrix}
    - \hat y
    \begin{vmatrix}
      \frac{\partial}{\partial x} & \frac{\partial}{\partial z} \\
      E_x & E_z
    \end{vmatrix}
    + \hat z
    \begin{vmatrix}
      \frac{\partial}{\partial x} & \frac{\partial}{\partial y} \\
      E_x & E_y
    \end{vmatrix}
    &= -\frac{\partial \mathbf{B}}{\partial t} \\
    \Rightarrow
    \left(\frac{\partial E_z}{\partial y} - \frac{\partial E_y}{\partial z}\right) \hat x
    - \left(\frac{\partial E_z}{\partial x} - \frac{\partial E_x}{\partial z}\right) \hat y       
    + \left(\frac{\partial E_y}{\partial x} - \frac{\partial E_x}{\partial y}\right) \hat z
    &= -\frac{\partial \mathbf{B}}{\partial t} \\
  \end{align*}
$$

Applying both assumptions cancels every term except one:
$$
  \begin{align*}
    \left( \bcancel{\frac{\partial E_z}{\partial y}} - \frac{\partial \cancel{E_y}}{\partial z} \right) \hat x
    - \left( \bcancel{\frac{\partial E_z}{\partial x}} - \frac{\partial E_x}{\partial z} \right) \hat y       
    + \left( \bcancel{\frac{\partial E_y}{\partial x}} - \bcancel{\frac{\partial E_x}{\partial y}} \right) \hat z
    &= -\frac{\partial \mathbf{B}}{\partial t} \\
    \Rightarrow
    \frac{\partial E_x}{\partial z} \hat y 
      &= -\frac{\partial \mathbf{B}}{\partial t}
  \end{align*}
$$

This implies that only the part of $\mathbf{B}$ in the $y$-direction is relevant.
$$
    \frac{\partial E_x}{\partial z} \, \hat y = -\frac{\partial B_y}{\partial t} \, \hat y
$$

<br />

<div class="important-note"><span class="icon">💡</span>

The rate of change in the electric field **in space** ($z$) is exactly balanced by the rate of change of the magnetic field **in time** ($t$)
$$
  \frac{\partial E_x}{\partial z} = -\frac{\partial B_y}{\partial t}
$$

where $\hat y$ points across the trace width — the direction $\mathbf B$ curls around the conductor.
</div>

<br />

---

<br />

### A.3 TEM Ratio

For a TEM wave propagating in $+\hat z$ at speed $v$, the electric and magnetic field amplitudes are not independent — they are locked together by Faraday's law (§A.2) plus the wave-speed constraint.

Start from the relationship between the rate of change in the electric field *in space* ($z$) and the rate of change of the magnetic field *in time* ($t$) (Appendix A.2):
<div class="quote">

$$
    \frac{\partial E_x}{\partial z} = -\frac{\partial B_y}{\partial t}
$$
</div>

**Apply the wavefront constraint:** Because the wave moves at speed $v$, the field follows the form $E_x(z-vt)$. This links the *change in time* to the *change in space*:
$$
  \frac{\partial E_x}{\partial t} = -v\, \frac{\partial E_x}{\partial z}
$$

So $\partial/\partial t = -v\,\partial/\partial z$ for any field quantity. Substitute on the right:
$$
    \frac{\partial E_x}{\partial z} = v\,\frac{\partial B_y}{\partial z}
$$

Integrate along $z$. Both $E_x$ and $B_y$ vanish ahead of the wavefront, so the integration constant is zero:
$$
    E_x = v\,B_y
$$

<div class="important-note"><span class="icon">💡</span>

The wave's electric and magnetic field amplitudes are tied by the propagation speed $v$: 
$$
  v = \frac{E_x}{B_y}
$$
</div>

<br />

---

<br />
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

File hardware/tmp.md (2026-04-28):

##### Boundary-condition view 1

Consider the EM wave traveling, through the dielectric, in the $+z$ direction at speed $v$. Ahead of the front, $E_x = 0$. Behind the front, we have $E_x$. At the front, there is a "sheet" of surface charge $\sigma_s$ to terminate the field lines of $E_x$ as we saw before.

**Wavefront constraint.** Because the wave moves at speed $v$ without changing shape, the field follows the form $E_x(z-vt)$. This links the change in time to the change in space:
$$
  \frac{\partial E_x}{\partial t} = -v\, \frac{\partial E_x}{\partial z}
$$

**Gauss's law** sets the surface charge density at the wavefront:
<div class="quote">

$$
    \sigma_s = \varepsilon\, E_x, \quad \text{in }\left[ \rm{C/m^2} \right]
$$
</div>

**Charge conservation** on the trace surface relates the surface current $K_z$ (arriving from behind the wavefront) to the rate at which $\sigma_s$ is being deposited at the front:
$$
  \frac{\partial K_z}{\partial z} + \frac{\partial \sigma_s}{\partial t} = 0
$$

Apply the wavefront constraint to $\partial \sigma_s/\partial t$:
$$
    \frac{\partial K_z}{\partial z} = -\frac{\partial \sigma_s}{\partial t} = v\, \frac{\partial \sigma_s}{\partial z}
$$

Integrate (with $K_z = 0$ ahead of the wavefront, where $\sigma_s = 0$):
$$
    K_z = v\, \sigma_s = \varepsilon\, v\, E_x, \quad \text{in }\left[ \rm{A/m} \right]
$$

----

The wave's electric and magnetic field amplitudes are not independent — they are locked together by the wave speed (Appendix A.3):
<div class="quote">

$$
    E_x = v\,B_y \tag{TEM ratio}
$$
</div>

Substituting $B_y = E_x / v$ for the RHS in the $K$ equation:
$$
  K_z = \frac{(E_x/v)}{\mu} = \frac{E_x}{\mu v}
$$

Recall Gauss's law applied to a thin pillbox straddling the conductor surface, the surface charge density $\sigma_s$:
<div class="quote"">

$$
  \sigma_s = \varepsilon\, E_x
$$
</div>

Substitude $E_x = \sigma_s / \varepsilon$ in the last $K_z$ equation
$$
  K_z = \frac{(\sigma_s / \varepsilon)}{\mu v}
$$

$$
  \newcommand{\shaded}[1]{\colorbox{##F7F7D2}{$\displaystyle #1$}}
  K_z = \frac{\sigma_s}{\mu\varepsilon v}
$$

**Cross-check.** The Ampère result $K_z = B_y/\mu$ and the continuity result $K_z = v\,\sigma_s$ are the same statement, once you use the TEM ratio $E_x = v\,B_y$ and Gauss's law $\sigma_s = \varepsilon E_x$:
$$
    K_z = \frac{B_y}{\mu} = \frac{E_x}{\mu v} = \varepsilon\, v\, E_x = v\,\sigma_s
$$
Ampère, Gauss, charge conservation, and the wave's $|\mathbf E|/|\mathbf B|$ ratio all agree on the same surface current.

---

**The TEM ratio.** The wave's electric and magnetic field amplitudes are not independent — they are locked together by the wave speed (Appendix A.3):
<div class="quote">

$$
    E_x = v\,B_y \tag{TEM ratio}
$$
</div>

---

<figure>
  <center>
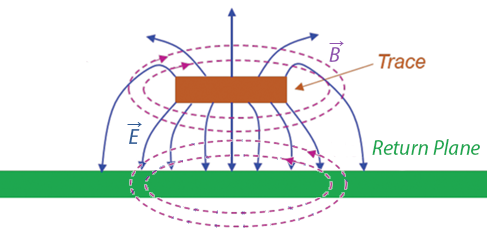
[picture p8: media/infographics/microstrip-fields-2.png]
  
  <figcaption><i>Cross-section view of Microstrip fields.<br />(Courtesy: Patrick André)</i></figcaption>
  </center>
</figure>

> **A note on field lines.** Textbook diagrams show fields as lines with arrows. These *field lines* are a visualization invented by Faraday, not physical objects. They are drawn by stepping from point to point in the direction the field vector points, with line density representing field strength. The field itself exists at *every* point in space — between the lines too. Where this document says "the $\mathbf E$ field points downward" or "the $\mathbf B$ field curls around the trace," it is shorthand for: the field vector at each point in that region has that direction and magnitude.

---

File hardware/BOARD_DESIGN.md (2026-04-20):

# Board Design Guide

This is the second document that answers **"How?"** — the companion to the Architecture document, and follow-up to the Schematic Design document. It covers the Printed Circuit Board (PCB) selection and layout rules for **OPNhydro**.

As in the Schematic Design document, the central problem remains **coexistence**.
- On one side: a pH probe measuring millivolt-level electrochemical potentials and an EC probe — both requiring a clean, quiet supply.
- On the other: three stepper drivers chopping current at 20–50 kHz, a buck converter switching at 1 MHz, a solenoid valve, and the ESP32 itself — which needs a clean supply but also generates digital switching noise and Wi-Fi TX bursts.

After the PCB selection and general layout rules, the document covers the different sections of the schematic.
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

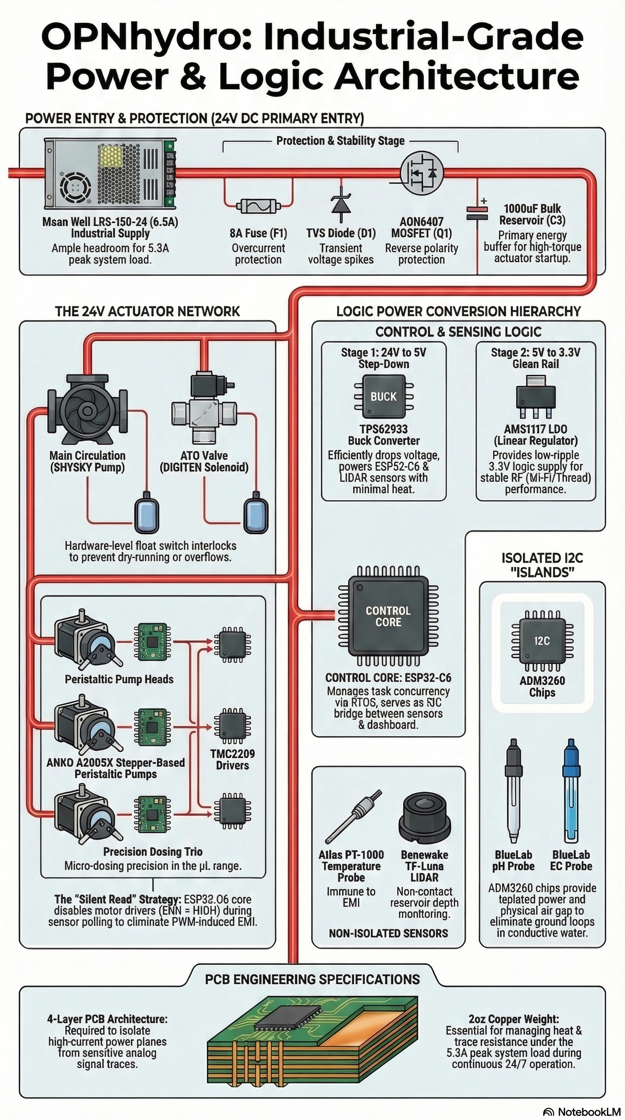
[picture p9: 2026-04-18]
media/infographics/hardware-architecture.png

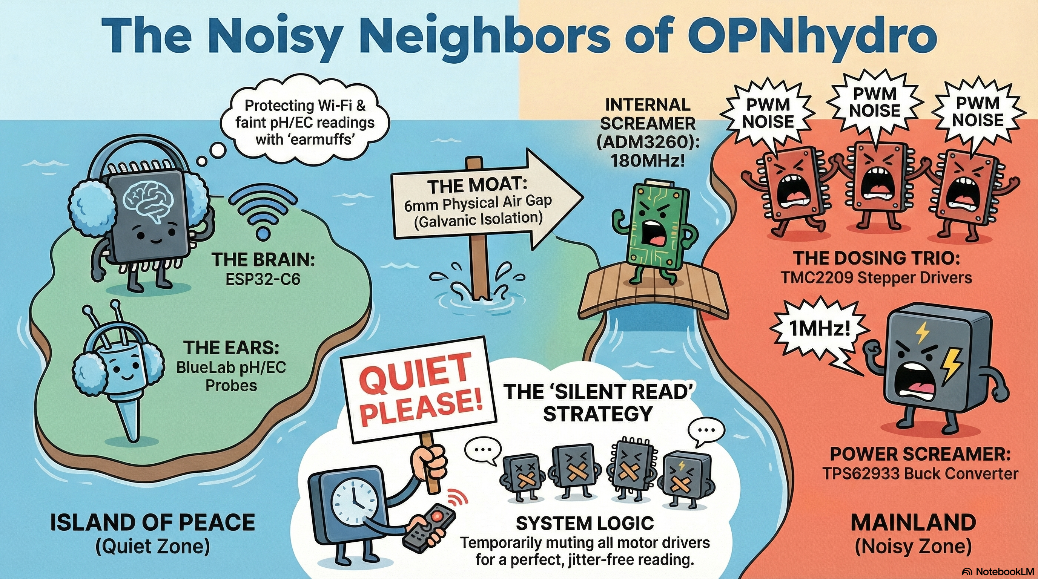
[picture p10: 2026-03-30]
media/infographics/electronic-noise.png

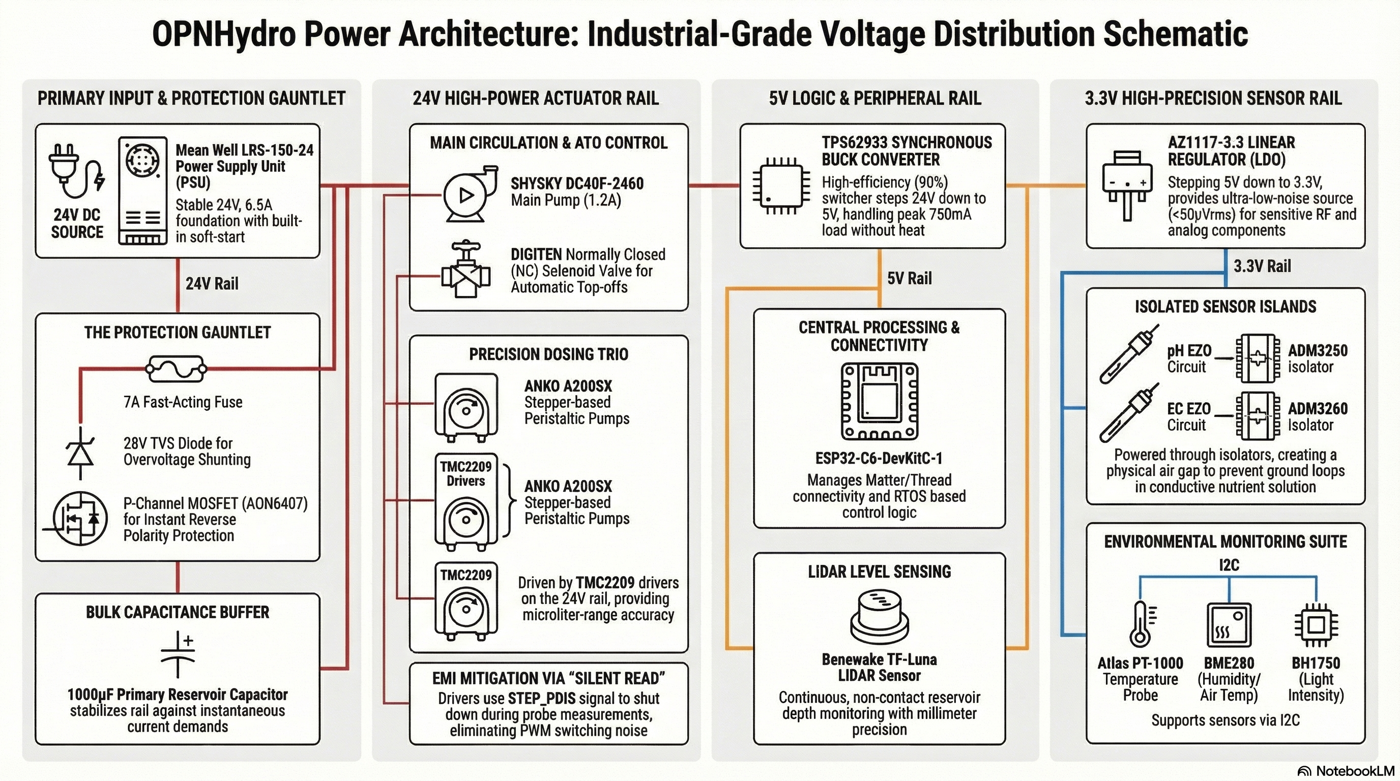
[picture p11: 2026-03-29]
media/infographics/power-architecture.png

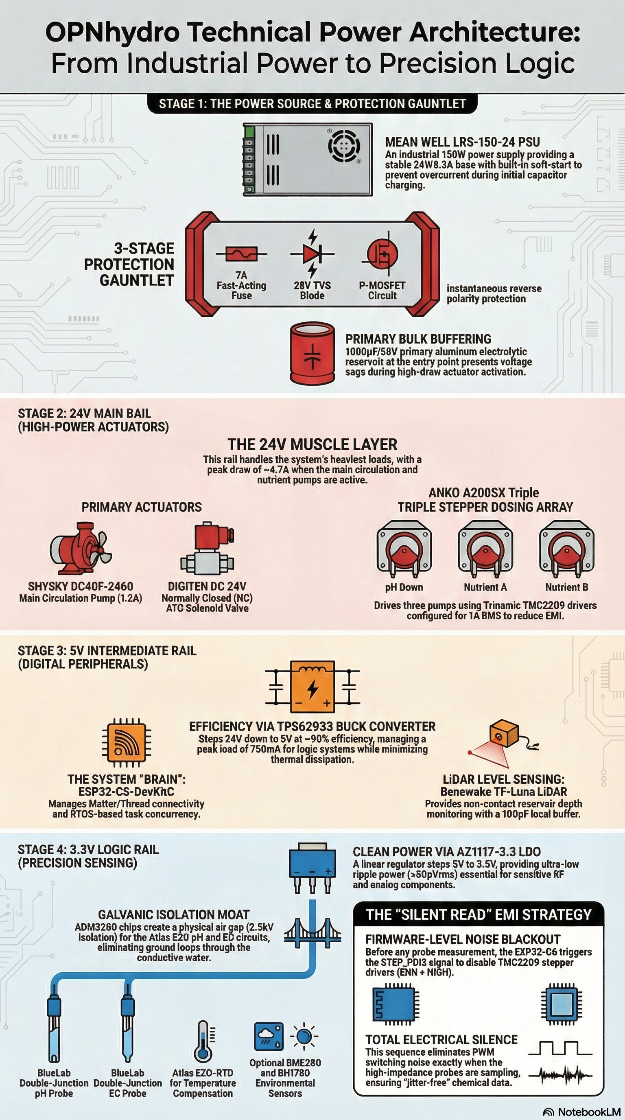
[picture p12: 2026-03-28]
media/infographics/power-architecture (2).png

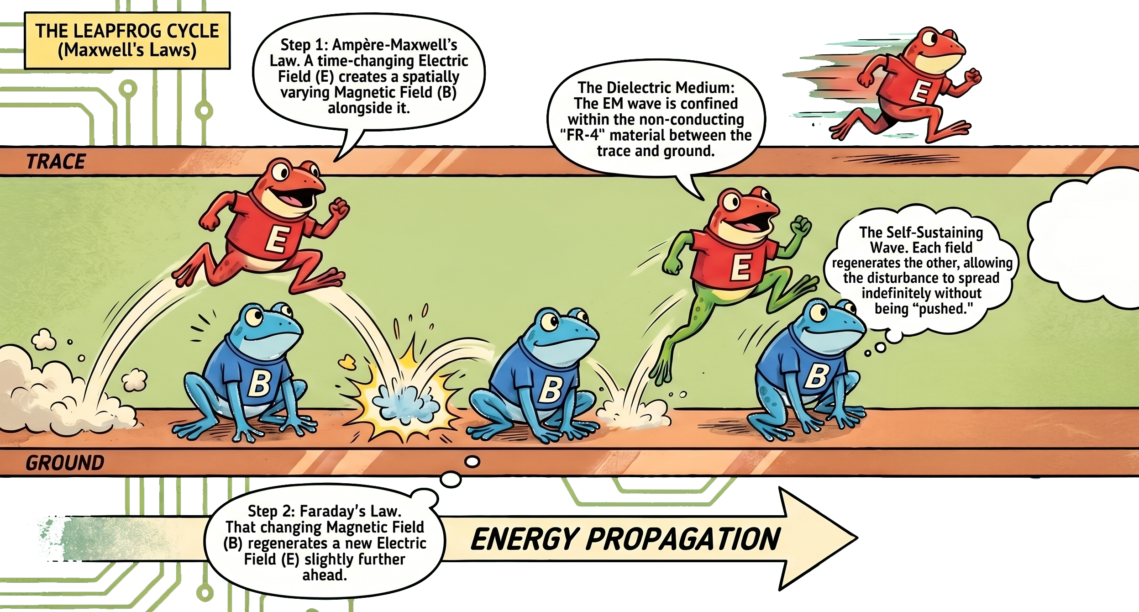
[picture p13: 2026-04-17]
media/infographics/e-b-leapfrog-2.png

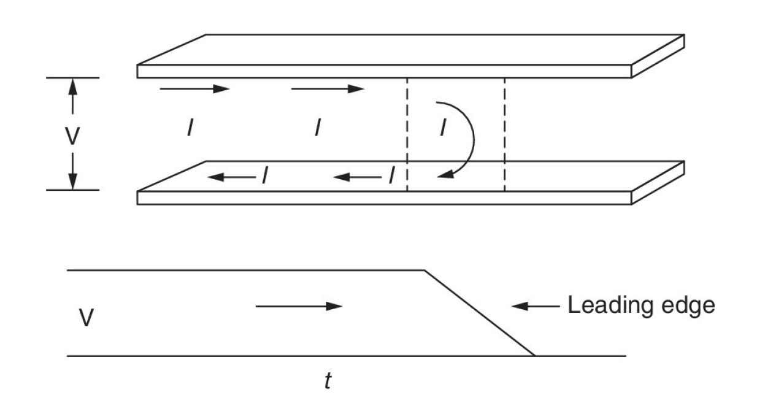
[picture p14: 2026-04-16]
media/infographics/current-in-a-wave-along-transmission-lines.png

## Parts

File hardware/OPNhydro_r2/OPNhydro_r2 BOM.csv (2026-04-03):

Reference | Qty | Value | DNP | Exclude from BOM | Exclude from Board | BLPN | DIGIKEY | PKG | SCLC | SERIES | LCSC
C1 | 1 | 100μ |  |  |  |  | 399-A750BK107M1AAAE024-ND | Radial |  | A750 | C1020041
C2,C58,C59,C60 | 4 | 220μ |  |  |  |  | 399-6123-ND | Radial |  | ESY | C5113406
C3,C4,C5,C8,C11,C12,C13,C18,C20,C22,C24,C28,C29,C32,C34,C37,C39,C43,C44,C45,C49,C50,C51,C52,C53,C54,C55,C56,C57 | 29 | 100n |  |  |  |  | 490-3285-1-ND | 0603 |  | GRM | C77058
C6 | 1 | 1000μ |  |  |  |  | B41866D6108M000 | Radial |  | B41866 | C1650604
C7 | 1 | 10μ |  |  |  |  | 490-12456-1-ND | 1206 |  | GRT | C417124
C9 | 1 | 47μ |  |  |  |  | 399-ESY476M050AE3AA-ND | Radial |  | ESY | C1019527
C10 | 1 | 33n |  |  |  |  | 399-C0603C333K5RACTUCT-ND | 0603 |  | SMD Comm X7R | C2169037
C14,C15,C16,C17,C19,C21,C30,C31,C36,C38 | 10 | 10μ |  |  |  |  | 490-3886-1-ND | 0805 |  | GRM | C77075
C23,C25,C33,C35 | 4 | 10n |  |  |  |  | 490-GRM188R72A103KA01JCT-ND | 0603 |  | GRM | C2187930
C26 | 1 | 220μ |  |  |  |  | P124158CT-ND | SMD |  | OS-CON, SVPK | C542293
C27 | 1 | 22μ |  |  |  |  |  | 1206 |  | GRM | C91604
C40,C41,C42 | 3 | 2μ2 |  |  |  |  | 490-6418-1-ND | 0603 |  | GRM | C2167658
C46,C47,C48 | 3 | 22n |  |  |  |  | 490-3284-1-ND | 0603 |  | GRM | C426087
D1,D4 | 2 | SS34 |  |  |  |  | SS34FSCT-ND | DO-214AB, SMC |  |  | C154551
D2 | 1 | 28V |  |  |  |  | SMBJ28A-FDICT-ND | DO-214AA |  | SMBJ | C91924
D3 | 1 | 12V |  |  |  |  | BZT52C12S-FDICT-ND | SOD-323 |  |  | C124208
DC1 | 1 | 24V/6.5A |  |  | Excluded from board |  | 1866-3321-ND |  |  | LRS-150 (150W) | C95193
F1 | 1 | 7A |  |  |  |  |  |  |  | NANO 451
FB1 | 1 | 50Ω@100Mhz |  |  |  |  | 490-13269-1-ND | 1206 |  | BLM31 | C710524
FB2,FB3,FB4,FB5 | 4 | 60Ω at 100MHz |  |  |  |  | 445-MPZ1608S600ATDH5CT-ND | 0603 |  | MPZ | C307775
FID1,FID2,FID3 | 3 | Fiducial |  | Excluded from BOM
H1 | 1 | PB_1.25mm |  |  |  |  | WM7624CT-ND |  |  | PicoBlade 53261 | C17393620
H2 | 1 | MSTBA_0.2" |  |  |  |  | 277-1106-ND |  |  | COMBICON MSTBA | C90074
H3,H4 | 2 | MC_0.2" |  |  |  |  | 277-6377-ND |  |  | COMBICON MC | C5355140
H5,H6 | 2 | JST_PH |  |  |  |  | 455-1721-ND |  |  | PH | C157926
H7,H8,H9 | 3 | JST_XH |  |  |  |  | 455-2243-ND |  |  | XH | C157925
J1 | 1 | SS-3.5mm |  |  |  |  | 2223-TB0011-350-04BE-ND |  |  | TB0011-350
J2,J3,J4 | 3 | BNC |  |  |  |  | A32259-ND
L1 | 1 | 10µ |  |  |  |  | SDR1307-100MLCT-ND | Nonstandard SMD |  |  | C49672242
M1 | 1 | ESP32-C6-DEVKIT |  |  |  |  | 1965-ESP32-C6-DEVKITC-1-N8-ND | Mezzanine |  | ESP32-C | C20554022
M2 | 1 | ATLAS_EZO_pH |  |  |  |  | 5016-EZO-PH-ND |  |  | EZO
M3 | 1 | ATLAS_EZO_EC |  |  |  |  | 5016-EZO-EC-ND |  |  | EZO
M4 | 1 | ATLAS_EZO_RTD |  |  |  |  | 5016-EZO-RTD-ND |  |  | EZO
MH1,MH2,MH3,MH4 | 4 | M3 |  | Excluded from BOM
P1 | 1 | PB_1.25mm |  |  | Excluded from board |  | WM1724-ND |  |  | PicoBlade 51021 | C385105
P2 | 1 | MSTB_0.2" |  |  | Excluded from board |  | 277-1011-ND |  |  | COMBICON MSTB | C90073
P3,P4 | 2 | MC_0.2" |  |  | Excluded from board |  | 277-6146-ND |  |  | MC
P5,P6 | 2 | PHR_4 | DNP |  | Excluded from board |  | 455-1164-ND |  |  | PH
P7,P8,P9 | 3 | XH_2.5mm |  |  | Excluded from board |  | 455-2267-ND |  |  | XH | C144403
PR1 | 1 | LiDAR |  |  | Excluded from board |  |  |  |  | TF
PR2 | 1 | BL_pH |  |  | Excluded from board | PROBPH
PR3 | 1 | BL_EC |  |  | Excluded from board | PROBPCEC
PR4 | 1 | ATLAS_RTD |  |  | Excluded from board |  | 5016-PT-1000-ND
PR5 | 1 | LIGHT | DNP |  | Excluded from board
PR6 | 1 | BME280 | DNP |  | Excluded from board
PUMP1 | 1 | DC40F-2460 |  |  | Excluded from board
PUMP2,PUMP3,PUMP4 | 3 | ANKO_A200SX |  |  | Excluded from board
R1,R10 | 2 | 100Ω |  |  |  |  | 311-100CRCT-ND | 0805 |  | RC_L | C105577
R2,R11 | 2 | 4k7 |  |  |  |  | 311-4.70KCRCT-ND | 0805 |  | RC_L | C60816
R3,R4,R16,R17,R18,R19 | 6 | 2k2 |  |  |  |  | 311-2.20KCRCT-ND | 0805 |  | RC_L | C114561
R5,R6,R9,R12,R15,R22,R23 | 7 | 10k |  |  |  |  | 311-10.0KCRCT-ND | 0805 |  | RC_L | C84376
R7 | 1 | 33k |  |  |  |  | 13-RC0805FR-1333KLCT-ND | 0805 |  | RC_L | C4245127
R8 | 1 | 1k |  |  |  |  | 311-1.00KCRCT-ND | 0805 |  | RC_L | C95781
R13 | 1 | 21k |  |  |  |  | 311-21.0KCRCT-ND | 0805 |  | RC_L | C137569
R14 | 1 | 52k3 |  |  |  |  | 311-52.3KCRCT-ND | 0805 |  | RC_L | C273887
R20,R21 | 2 | 16k9 |  |  |  |  | 311-16.9KCRCT-ND | 0805 |  | RC_L | C273834
R24,R26,R28 | 3 | 14k |  |  |  |  | 13-RC0805FR-1014KLCT-ND | 0805 |  | RC_L | C4347440
R25,R27,R29 | 3 | 10k7 |  |  |  |  | 311-10.7KCRCT-ND | 0805 |  | RC_L | C273918
R30,R31,R32,R33,R34,R35 | 6 | 110mΩ |  |  |  |  | RL12S.11FCT-ND | 0805 |  | RL | C2074624
SW1,SW2 | 2 | FLOAT |  |  | Excluded from board
T1,T4 | 2 | BT3904 |  |  |  |  | MMBT3904LT1GOSCT-ND | SOT-23-3 |  |  | C81464
T2 | 1 | IRLR2905 |  |  |  |  | IRLR2905PBFCT-ND | TO-252AA (DPAK) |  | HEXFET | C3010
T3 | 1 | AON6407 |  |  |  |  | 785-1421-1-ND | 8-DFN (5x6) |  |  | C13899
T5 | 1 | AO3400A |  |  |  |  | 785-1000-1-ND | SOT-23-3 |  |  | C20917
TP1,TP2,TP3,TP4,TP5,TP6 | 6 | TestPoint
U1 | 1 | TPS62933 |  |  |  |  | 296-TPS62933DRLRCT-ND | SOT-583 |  |  | C3200405
U2 | 1 | AZ1117-3.3 |  |  |  |  | AZ1117IH-3.3TRG1DICT-ND | SOT-223-3 |  | AZ1117I | C108495
U3,U4 | 2 | ADM3260 |  |  |  |  | 505-ADM3260ARSZ-ND | 20-SSOP |  | IsoPower | C208558
U5,U6,U7 | 3 | TMC2209 |  |  |  |  | 175-TMC2209-LA-TCT-ND | 28-VFQFN Exposed Pad |  | stallGuard | C2150710
V1 | 1 | DIGITEN-24V |  |  | Excluded from board

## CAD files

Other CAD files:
hardware/CST_Studio/microstrace_timedomain/ModelCache/Model.psm
hardware/CST_Studio/microstrace_timedomain_copper/ModelCache/Model.psm
hardware/CST_Studio/microstrace_timedomain_copper/Result/Port1_e1.prt
hardware/CST_Studio/microstrace_timedomain_copper/Result/Port1_e1[12.5].prt
hardware/CST_Studio/microstrace_timedomain_copper/Result/Port1_h1.prt
hardware/CST_Studio/microstrace_timedomain_copper/Result/Port1_h1[12.5].prt
hardware/CST_Studio/microstrace_timedomain_copper/Result/adapt_Port1_e1.prt
hardware/CST_Studio/microstrace_timedomain_copper/Result/adapt_Port1_e1[12.5].prt
hardware/CST_Studio/microstrace_timedomain_copper/Result/adapt_Port1_h1.prt
hardware/CST_Studio/microstrace_timedomain_copper/Result/adapt_Port1_h1[12.5].prt
hardware/CST_Studio/microtrace/ModelCache/Model.psm
hardware/CST_Studio/microtrace/Result/Port1_e1.prt
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

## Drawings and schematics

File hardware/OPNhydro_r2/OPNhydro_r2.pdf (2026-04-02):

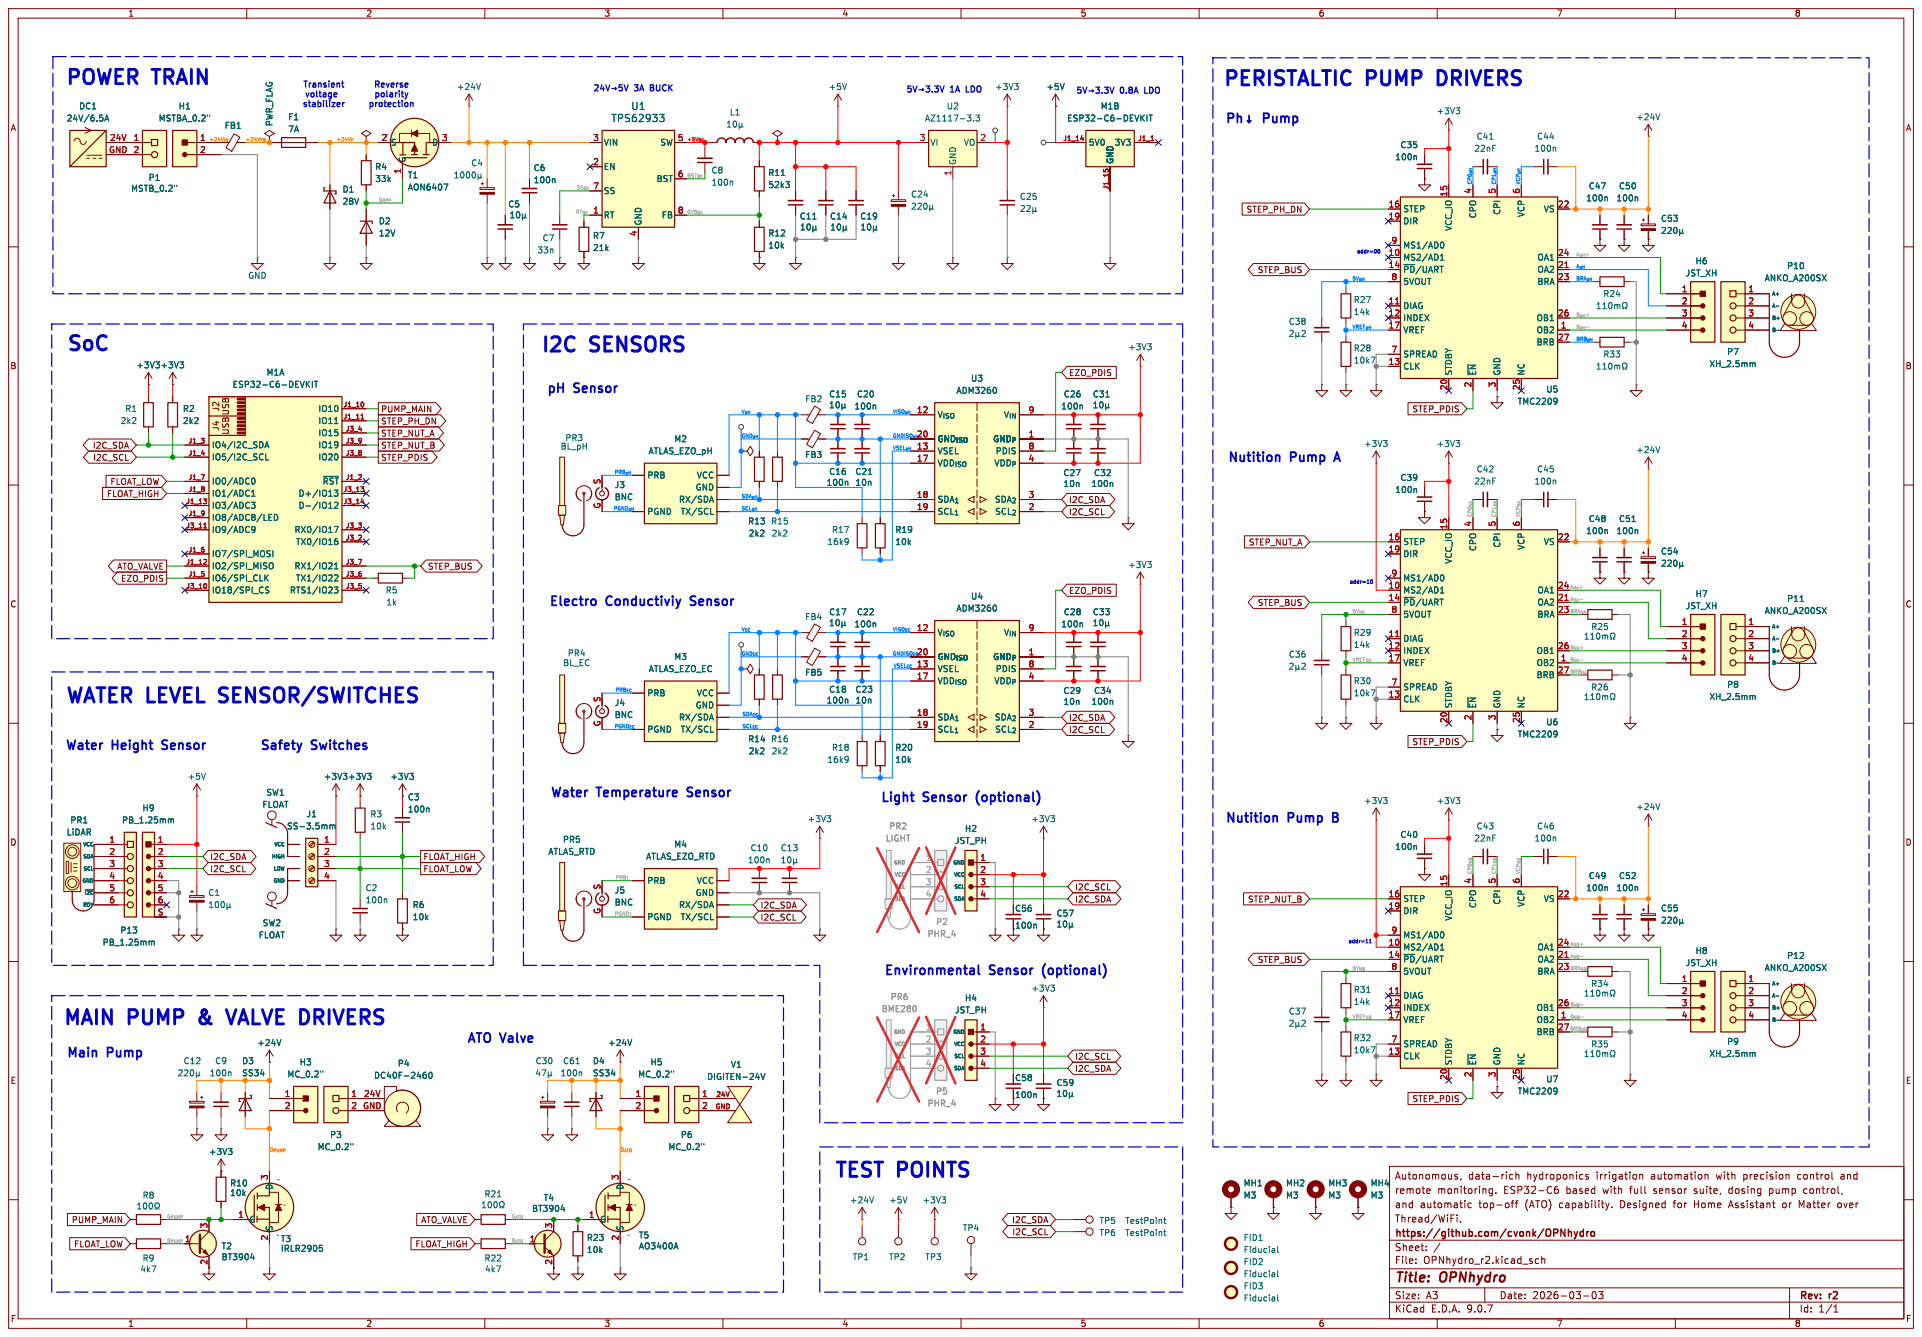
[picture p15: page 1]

STEP 16 DIR 19 MS1/AD0 9 MS2/AD1 10 ~{PD}/UART 14

6 NC 25 VS 22 OA1 24 OA2 21 BRA 23 OB1 26 OB2 1 BRB 27 U5 TMC2209 C41

6 NC 25 VS 22 OA1 24 OA2 21 BRA 23 OB1 26 OB2 1 BRB 27 C39

6 NC 25 VS 22 OA1 24 OA2 21 BRA 23 OB1 26 OB2 1 BRB 27 U5 TMC2209 STEP 16 DIR 19 MS1/AD0 9 MS2/AD1 10 ~{PD}/UART 14

VSEL_{EC} GNDISO_{EC} VISO_{EC} VSEL_{pH} VISO_{pH}

5V_{NA} SDA_{pH} SDA_{EC} SCL_{pH} GND_{pH} PGND_{EC} PRB_{EC}

6 NC 25 VS 22 OA1 24 OA2 21 BRA 23 OB1 26 OB2 1 BRB 27 U6 TMC2209 +24V

Nutition Pump A
A+A- B+B- U6 TMC2209 STEP 16 DIR 19 MS1/AD0 9 MS2/AD1 10 ~{PD}/UART 14

B_{NA}- B_{NA}+ BRB_{NA} PRB_{pH}
J3BNC

WATER LEVEL SENSOR/SWITCHES

6 NC 25 VS 22 OA1 24 OA2 21 BRA 23 OB1 26 OB2 1 BRB 27 U7 TMC2209 C49

6 NC 25 VS 22 OA1 24 OA2 21 BRA 23 OB1 26 OB2 1 BRB 27 C49

U7 TMC2209 STEP 16 DIR 19 MS1/AD0 9 MS2/AD1 10 ~{PD}/UART 14

File: OPNhydro_r2.kicad_sch Sheet: / https://github.com/cvonk/OPNhydro

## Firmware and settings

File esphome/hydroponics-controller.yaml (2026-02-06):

# OPNhydroponics - ESP32-C6 NFT Hydroponics Controller
# ESPHome configuration for Home Assistant integration

substitutions:
  device_name: hydroponics-controller
  friendly_name: "Hydroponics Controller"

  # Calibration values (adjust after calibration)
  ph_offset: "0.0"
  ec_offset: "0.0"

  # Tank dimensions for volume calculation (cm)
  tank_height: "40"
  tank_length: "60"
  tank_width: "40"

  # Dosing pump flow rates (mL per second)
  pump_ph_up_rate: "1.5"
  pump_ph_down_rate: "1.5"
  pump_nutrient_a_rate: "2.0"
  pump_nutrient_b_rate: "2.0"

esphome:
  name: ${device_name}
  friendly_name: ${friendly_name}
  comment: "NFT Hydroponics monitoring and control system"
  project:
    name: "opn.hydroponics"
    version: "1.0.0"
  on_boot:
    priority: 600
    then:
      - light.turn_on:
          id: status_led
          effect: "Slow Pulse"
          red: 0%
          green: 0%
          blue: 100%
      - delay: 5s
      - light.turn_on:
          id: status_led
          red: 0%
          green: 100%
          blue: 0%

esp32:
  board: esp32-c6-devkitc-1
  framework:
    type: esp-idf
    version: "5.1.2"
    platform_version: 6.5.0

# Enable logging
logger:
  level: INFO
  logs:
    component: ERROR  # Reduce noise

# Enable Home Assistant API
api:
  encryption:
    key: !secret api_encryption_key
  services:
    # Manual dosing service
    - service: dose_pump
      variables:
        pump: int
        duration_ms: int
      then:
        - lambda: |-
            switch(pump) {
              case 1: id(pump_ph_up).turn_on(); break;
              case 2: id(pump_ph_down).turn_on(); break;
              case 3: id(pump_nutrient_a).turn_on(); break;
              case 4: id(pump_nutrient_b).turn_on(); break;
            }
        - delay: !lambda 'return duration_ms;'
        - lambda: |-
            switch(pump) {
              case 1: id(pump_ph_up).turn_off(); break;
              case 2: id(pump_ph_down).turn_off(); break;
              case 3: id(pump_nutrient_a).turn_off(); break;
              case 4: id(pump_nutrient_b).turn_off(); break;
            }

    # Calibrate pH service
    - service: calibrate_ph
      variables:
        point: string  # "low", "mid", "high"
        value: float   # 4.0, 7.0, or 10.0
      then:
        - lambda: |-
            // Send calibration command to EZO circuit
            // Format: Cal,mid,7.00 or Cal,low,4.00 or Cal,high,10.00
            char cmd[20];
            snprintf(cmd, sizeof(cmd), "Cal,%s,%.2f", point.c_str(), value);
            // id(ezo_ph).send_command(cmd);
            ESP_LOGI("calibration", "pH calibration: %s", cmd);

ota:
  - platform: esphome
    password: !secret ota_password

wifi:
  ssid: !secret wifi_ssid
  password: !secret wifi_password

  # Enable fallback hotspot
  ap:
    ssid: "${device_name} Fallback"
    password: !secret ap_password

captive_portal:

# Web server for local access
web_server:
  port: 80
  local: true

# I2C bus for sensors
i2c:
  sda: GPIO1
  scl: GPIO2
  scan: true
  frequency: 100kHz

# 1-Wire bus for temperature sensors
one_wire:
  - platform: gpio
    pin: GPIO3

# Home Assistant time for scheduling
time:
  - platform: homeassistant
    id: homeassistant_time
    on_time:
      # Reset daily dose counters at midnight
      - seconds: 0
        minutes: 0
        hours: 0
        then:
          - lambda: |-
              id(daily_ph_up_dosed) = 0;
              id(daily_ph_down_dosed) = 0;
              id(daily_nutrient_dosed) = 0;
              ESP_LOGI("dosing", "Daily dose counters reset");

# =============================================================================
# GLOBALS (State Variables)
# =============================================================================

globals:
  # Dosing lockout timestamps (millis)
  - id: last_ph_dose_time
    type: unsigned long
    restore_value: no
    initial_value: '0'

  - id: last_ec_dose_time
    type: unsigned long
    restore_value: no
    initial_value: '0'

  # Daily dose tracking (mL)
  - id: daily_ph_up_dosed
    type: float
    restore_value: no
    initial_value: '0'

  - id: daily_ph_down_dosed
    type: float
    restore_value: no
    initial_value: '0'

  - id: daily_nutrient_dosed
    type: float
    restore_value: no
    initial_value: '0'

  # ATO state
  - id: ato_pending
    type: bool
    restore_value: no
    initial_value: 'false'

  - id: ato_approved
    type: bool
    restore_value: no
    initial_value: 'false'

  - id: ato_fill_start_time
    type: unsigned long
    restore_value: no
    initial_value: '0'

  # Local automation enable flags
  - id: local_ph_control_enabled
    type: bool
    restore_value: yes
    initial_value: 'true'

  - id: local_ec_control_enabled
    type: bool
    restore_value: yes
    initial_value: 'true'

# =============================================================================
# SENSORS
# =============================================================================
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
